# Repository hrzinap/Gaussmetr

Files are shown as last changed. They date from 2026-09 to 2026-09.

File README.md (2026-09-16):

# Gaussmetr
## Elixír do škol 2026
Archiv obsahuje potřebné soubory pro výrobu jednoduchého magnetometru (využívajícího Hallův senzor)
Jsou zde dostupné zdrojové kódy desky pro případné zpracování výrobních podkladů (formát KiCad 10)
Je použit klon desky Arduino NANO s procesorem Čínské výroby [LGT8f328p](https://wolles-elektronikkiste.de/lgt8f328p-lqfp32-boards).
K tomuto klonu je nutné stáhnout do vývojového prostředí Arduino IDE definici desky a základních knihoven.
[Více GitHub](https://github.com/dbuezas/lgt8fx)
Použití tohto procesoru umožní využít kombinace D/A a A/D převodníku pro kompenzaci ofsetu Hallova čidla. 
Navrženou desku plošných spojů lze použít i pro běžné Arduino NANO, ale je nutná úprava řídicího SW a bez dalších HW úprav se bude obtížně dosahovat symetrie měření. Nic méně sestava bude pro demonstrační účely použitelná.

pohled_na_gaussmetr

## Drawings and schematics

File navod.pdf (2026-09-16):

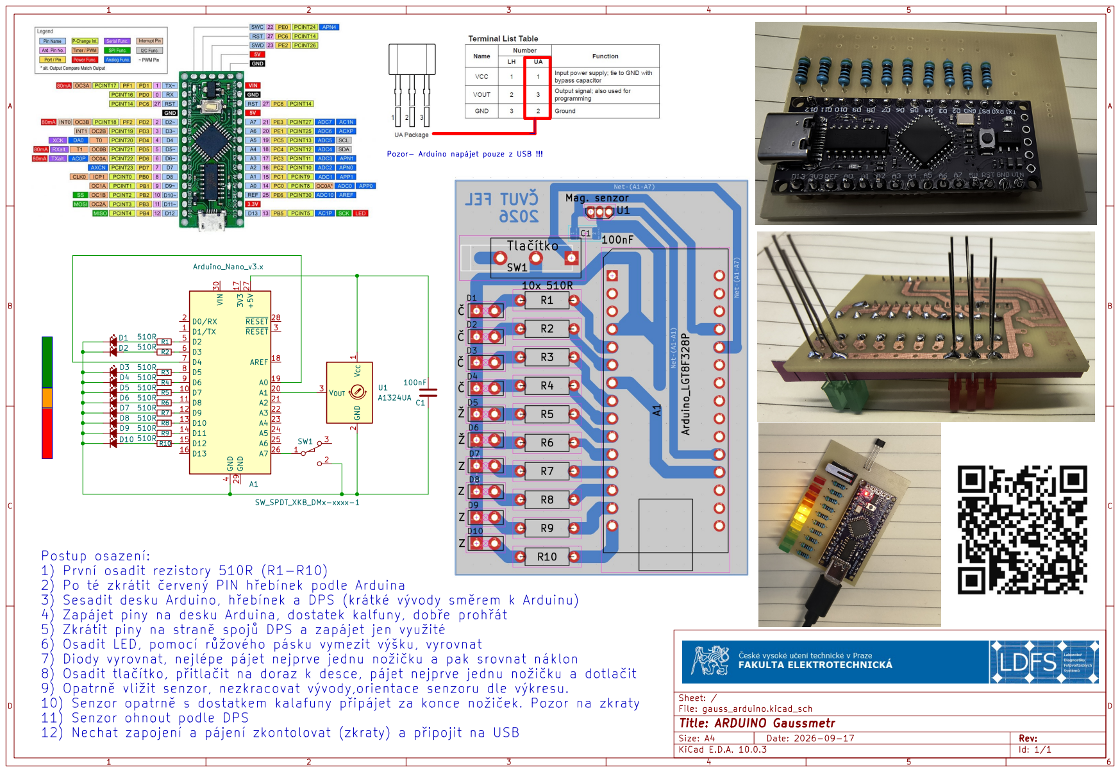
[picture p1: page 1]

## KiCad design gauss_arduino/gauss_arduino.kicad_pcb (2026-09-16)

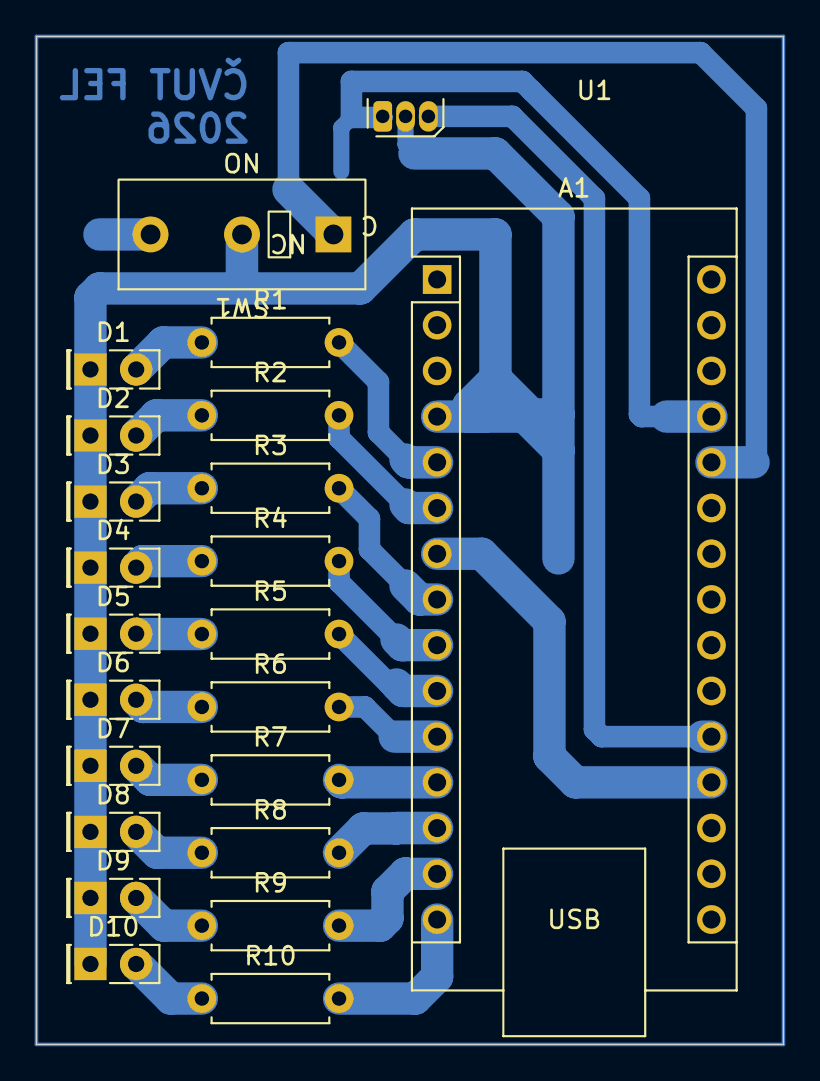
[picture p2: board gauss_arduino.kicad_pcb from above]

Board: 2 copper layers, 41.5 x 56.0 mm, 24 parts (1 on the bottom side), 25 nets.

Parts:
A1: Arduino_LGT8F328P; Arduino_Nano
C1: 100nF; C_1206_3216Metric_Pad1.33x1.80mm_HandSolder
D1, D2, D3, D4: Č; LED_Rectangular_W5.0mm_H2.0mm
D5, D6: Ž; LED_Rectangular_W5.0mm_H2.0mm
D7, D8, D9, D10: Z; LED_Rectangular_W5.0mm_H2.0mm
R1: 10x 510R; R_Axial_DIN0207_L6.3mm_D2.5mm_P7.62mm_Horizontal
R2, R3, R4, R5, R6, R7, R8, R9, R10: R_Axial_DIN0207_L6.3mm_D2.5mm_P7.62mm_Horizontal
SW1: SW_XKB_DM1-16UP-1
U1: Mag. senzor; TO-92S

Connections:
unnamed: A1.27 (+5V), C1.1, U1.1 (V_{CC})
unnamed: A1.7 (D4), A1.19 (A0)
unnamed: A1.20 (A1), U1.3 (V_{OUT})
unnamed: A1.26 (A7), SW1.1 (A)
unnamed: A1.5 (D2), R1.2
unnamed: A1.6 (D3), R2.2
unnamed: A1.8 (D5), R3.2
unnamed: A1.9 (D6), R4.2
unnamed: A1.10 (D7), R5.2
unnamed: A1.11 (D8), R6.2
unnamed: A1.12 (D9), R7.2
unnamed: A1.13 (D10), R8.2
unnamed: A1.14 (D11), R9.2
unnamed: A1.15 (D12), R10.2
unnamed: D1.2 (A), R1.1
unnamed: A1.4 (GND), C1.2, D1.1 (K), D2.1 (K), D3.1 (K), D4.1 (K), D5.1 (K), D6.1 (K), D7.1 (K), D8.1 (K), D9.1 (K), D10.1 (K), SW1.2 (B), U1.2 (GND)
unnamed: D2.2 (A), R2.1
unnamed: D3.2 (A), R3.1
unnamed: D4.2 (A), R4.1
unnamed: D5.2 (A), R5.1
unnamed: D6.2 (A), R6.1
unnamed: D7.2 (A), R7.1
unnamed: D8.2 (A), R8.1
unnamed: D9.2 (A), R9.1
unnamed: D10.2 (A), R10.1

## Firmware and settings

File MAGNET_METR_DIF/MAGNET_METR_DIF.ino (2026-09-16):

#include<differential_amplifier.h>
/*
    Parameter:      Reference:
    DEFAULT         VCC
    EXTERNAL        External Reference (REF)
    INTERNAL1V024   Internal 1.024 volts
    INTERNAL2V048   Internal 2.048 volts
    INTERNAL4V096   Internal 4.096 volts
  
  Citlivost(zesileni): B=0 -> 2,5V, max. rozsah A/D 4.096V
  senzor 5mV/G
  10 rozsahu k dispozici:
  Ind. rozsah +/-  nasobitel
  -9    2,50V       x 3,6 
  -7    2,25V       x 4
  -5    2,00V       x 4,5 
  -3    1,75V       x 5,14
  -1    1,50V       x 6 
  1     1,25V       x 7,2
  3     1,00V       x 9
  5     0,75V       x 12
  7     0,50V       x 18
  9     0,25V       x 36
*/
const float zesileni[10] = {3.6, 4, 4.5, 5.14, 6, 7.2, 9, 12, 18, 36};
const int zesLed[10] = {-9, -7, -5, -3, -1, 1, 3, 5, 7, 9};
float value0 = 2.4;  //hodnota napeti odpovidajici 0T  (predpokladana hodnota)
float value1 = 2;  //hodnota napeti odpovidajici vystupu DAC (prepokladan hodnota)
int zesind = 0; //vychozi zesileni (index)
int daci = 25; // nastaveni DAC prevodniku, střed
// *************************************************
// Zhasnutí všech LED
void LedOff() {
  digitalWrite(2, LOW);
  digitalWrite(3, LOW);
  digitalWrite(5, LOW);
  digitalWrite(6, LOW);
  digitalWrite(7, LOW);
  digitalWrite(8, LOW);
  digitalWrite(9, LOW);
  digitalWrite(10, LOW);
  digitalWrite(11, LOW);
  digitalWrite(12, LOW);
  digitalWrite(13, LOW);
}
// *************************************************
// Rozsvícení všech LED
void LedOn() {
  digitalWrite(2, HIGH);
  digitalWrite(3, HIGH);
  digitalWrite(5, HIGH);
  digitalWrite(6, HIGH);
  digitalWrite(7, HIGH);
  digitalWrite(8, HIGH);
  digitalWrite(9, HIGH);
  digitalWrite(10, HIGH);
  digitalWrite(11, HIGH);
  digitalWrite(12, HIGH);
  digitalWrite(13, LOW);
}
// *************************************************
// Testování LED - probliknutí
void ledTest(){
   LedOn();
   delay(200);
   LedOff();
   delay(200);
   LedOn();
   delay(200);
   LedOff();
   delay(200);
   LedOn();
   delay(200);
   LedOff();

}
// *************************************************
// Aktualizace LED Bargrafu a zároveň výpis na RS232
// @param index rozsah -9 až +9 
// 9 - - - | x0x | - -  -9 
void LedOutput(int index) {
  switch (index) {
    case 0:
      digitalWrite(8, HIGH);
      digitalWrite(7, HIGH);
      Serial.print(F("- - - - | x x | - - - -"));
    break;
    case 1:
      digitalWrite(7, HIGH);
      Serial.print(F("- - - - | x - | - - - -"));
    break;
    case 2:
      digitalWrite(7, HIGH);
      digitalWrite(6, HIGH);
      Serial.print(F("- - - x | x - | - - - -"));
    break;
    case 3:
      digitalWrite(6, HIGH);
      Serial.print(F("- - - x | - - | - - - -"));
    break;
    case 4:
      digitalWrite(6, HIGH);
      digitalWrite(5, HIGH);
      Serial.print(F("- - x x | - - | - - - -"));
    break;
    case 5:
      digitalWrite(5, HIGH);
      Serial.print(F("- - x - | - - | - - - -"));
    break;
    case 6:
      digitalWrite(5, HIGH);
      digitalWrite(3, HIGH);
      Serial.print(F("- x x - | - - | - - - -"));
    break;
    case 7:
      digitalWrite(3, HIGH);
      Serial.print(F("- x - - | - - | - - - -"));
    break;
    case 8:
      digitalWrite(3, HIGH);
      digitalWrite(2, HIGH);
      Serial.print(F("x x - - | - - | - - - -"));
    break;
    case 9:
      digitalWrite(2, HIGH);
      Serial.print(F("x - - - | - - | - - - -"));
    break;
    case -1:
      digitalWrite(8, HIGH);
      Serial.print(F("- - - - | - x | - - - -"));
    break;
    case -2:
      digitalWrite(8, HIGH);
      digitalWrite(9, HIGH);
      Serial.print(F("- - - - | - x | x - - -"));
    break;
    case -3:
      digitalWrite(9, HIGH);
      Serial.print(F("- - - - | - - | x - - -"));
    break;
    case -4:
      digitalWrite(9, HIGH);
      digitalWrite(10, HIGH);
      Serial.print(F("- - - - | - - | x x - -"));
    break;
    case -5:
      digitalWrite(10, HIGH);
      Serial.print(F("- - - - | - - | - x - -"));
    break;
    case -6:
      digitalWrite(10, HIGH);
      digitalWrite(11, HIGH);
      Serial.print(F("- - - - | - - | - x x -"));
    break;
    case -7:
      digitalWrite(11, HIGH);
      Serial.print(F("- - - - | - - | - - x -"));
    break;
    case -8:
      digitalWrite(11, HIGH);
      digitalWrite(12, HIGH);
      Serial.print(F("- - - - | - - | - - x x"));
    break;
    case -9:
      digitalWrite(12, HIGH);
     Serial.print(F("- - - - | - - | - - - x"));
    break;    
    default: 
      digitalWrite(13, HIGH);
      Serial.print(F("- -prekrocen rozsah- -"));
    break; 

  }
}
// *************************************************
// Nastavení citlivosti
// modifikuje zesind - index pro nastavení zesílení
// ovládání: stisk tlačítka, držet dokud nesvítí  LED
// odpovídající danému zesílení. Po RST zesind=0;
void citlivost() {
  LedOff();
  LedOutput(zesLed[zesind]);
  Serial.print(F(" Zes: "));
  Serial.println(zesind);
  while (!digitalRead(A7)) {
    if (!digitalRead(A7)) {
      if (zesind < 9 ) {
        zesind = zesind+1;
        } else {
        zesind = 0;
      };
      LedOff();
      LedOutput(zesLed[zesind]);
      Serial.print(F(" Zes: "));
      Serial.println(zesind);
      delay(1000);
    }
  }
}
// *************************************************
// SETUP systému, nastavení prostředí (začátek programu)
void setup() {
  // put your setup code here, to run once:
  int raw = 0;
  pinMode(2, OUTPUT);
  digitalWrite(2, LOW);
  pinMode(3, OUTPUT);
  digitalWrite(3, LOW);
  pinMode(5, OUTPUT);
  digitalWrite(5,LOW);
  pinMode(6, OUTPUT);
  digitalWrite(6, LOW);
  pinMode(7, OUTPUT);
  digitalWrite(7, LOW);
  pinMode(8, OUTPUT);
  digitalWrite(8, LOW);
  pinMode(9, OUTPUT);
  digitalWrite(9,LOW);
  pinMode(10, OUTPUT);
  digitalWrite(10, LOW);
  pinMode(11, OUTPUT);
  digitalWrite(11, LOW);
  pinMode(12, OUTPUT);
  digitalWrite(12, LOW);
  pinMode(13, OUTPUT);
  digitalWrite(13, LOW);
  pinMode(A7,INPUT_PULLUP);
  // nastaveni PIN dokonceno
  analogReference(INTERNAL4V096);   //reference 4,096V
  analogReadResolution(12); // Resolution = 10, 11 or 12 Bit
  //možnost nastavit DAC pro diferenciální mód. 
  //Viz https://wolles-elektronikkiste.de/lgt8f328p-lqfp32-boards
  pinMode(DAC0, ANALOG);     
  analogWrite(DAC0, daci); // 0...255
  Serial.begin(9600);
  delay(1000);
  ledTest();  //probliknutí LED
  Serial.println(F("Boot... O.K."));
  while ((abs(raw-2048))>40) {    //smyčka nastavi offset sondy
    digitalWrite(13, HIGH);   // priznak nastavení, blikáme
    delay(100);
    digitalWrite(13, LOW);
    delay(100);
    raw = analogDiffRead(A0,A1,GAIN_1); // GAIN_x mit x = 1, 8, 16, 32
    Serial.print(F("RAW hodnota A0-A1: "));
    Serial.print(raw);
    Serial.print(F(" at DAC index: "));
    Serial.println(daci);
    if (raw>2048) {      //upravime DAC index
      daci = daci + 1;
      if (daci>254) daci=254;
    } else {
      daci = daci - 1;
      if (daci<1) daci=1;
    }
    analogWrite(DAC0, daci); // 0...255
  }

  Serial.println(F("DAC prevodnik nastaven"));
  raw = analogDiffRead(A0,A1,GAIN_1); // GAIN_x mit x = 1, 8, 16, 32
  Serial.println(raw);
  value0 = raw / 1024.0; // considers resolution, reference and gain
  Serial.print(F("Napeti nuloveho pole po korekci: "));
  Serial.print(value0,3);
  Serial.println(F(" V"));
  delay(1000);
}
// *************************************************
// Hlavní smyčka
void loop() {
  // put your main code here, to run repeatedly:
  delay(100); //cekani - uprava rychlosti smycky
  LedOff(); //zhasne LED - ctení AD bez rušení
  delay(1); //pauza, ustaleni zdroje
  int adcValue = analogDiffRead(A0,A1,GAIN_1); // GAIN_x mit x = 1, 8, 16, 32
  float voltage = (adcValue / 1024.0)- value0;  // Voltage calculation
  LedOutput(voltage * zesileni[zesind]); // aktualizace LED,bargraf i na RS232
  Serial.print(F(" Zes: ")); // tisky hodnot
  Serial.print(zesind);
  Serial.print(F("  Analog Value: "));
  Serial.print(adcValue);
  Serial.print(F("  Voltage [V]: "));
  Serial.println(voltage,3);
  if (!digitalRead(A7)) citlivost(); //obsluha tlacitka    
}

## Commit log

2026-09-16 Zdrojový kód Arduino
2026-09-16 Deska plošných spojů a schéma
    [gauss_arduino.kicad_pcb, gauss_arduino.kicad_sch]
